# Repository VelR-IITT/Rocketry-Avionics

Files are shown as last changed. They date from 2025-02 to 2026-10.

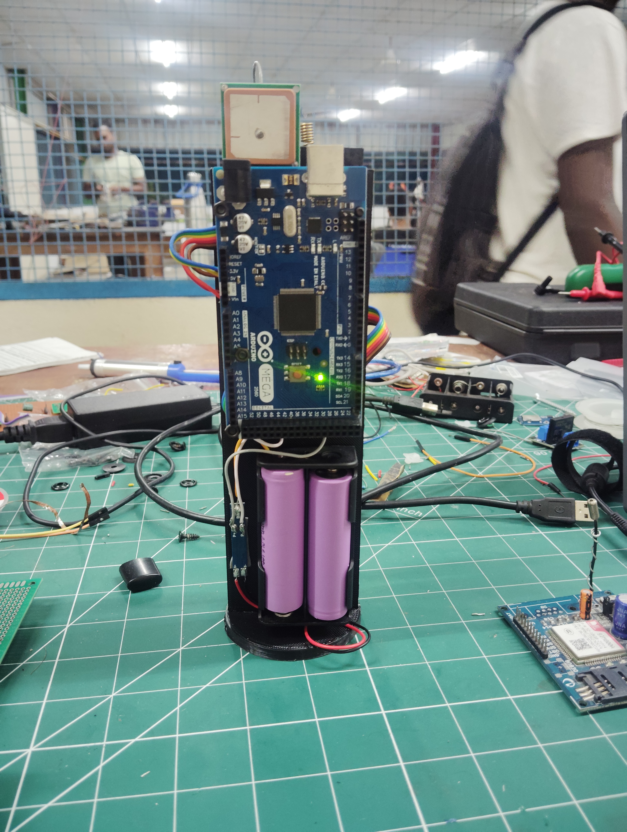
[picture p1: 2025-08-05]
Images and Files/actual/IMG_20250521_003605 (1).jpg

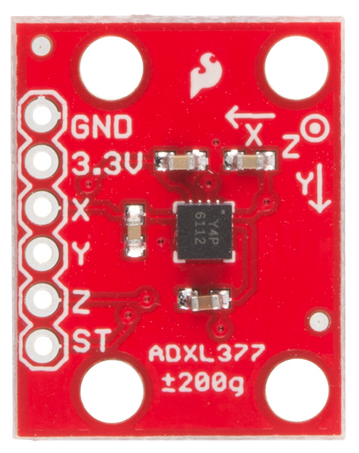
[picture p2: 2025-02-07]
Images and Files/actual/ADXL377-actual.png

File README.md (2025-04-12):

# Rocketry-Avionics 🚀

Welcome to the **Rocketry-Avionics** repository! This project is dedicated to the development of avionics systems for rocketry. It contains all the necessary files, code, and documentation to help you understand, build, and contribute to the project. 
---
## 📁 Repository Contents

This repository contains the following:

### 1. **Images** 📷
Contains visual assets, diagrams, and photos related to the project. These images are useful for understanding the design and assembly of components.

### 2. **Files for Components** 📄
Includes schematics, datasheets, and design files for various components used in the avionics system. These files are essential for replicating or modifying the project.

### 3. **Code** 💻
Contains the source code for the avionics system. This includes firmware, scripts, and any software required to operate the rocket's electronics.

### 4. **Instructions** 📝
Step-by-step guides and documentation to help you set up, assemble, and troubleshoot the avionics system.

---

## 📧 Contact

🌐 GitHub: [Pratham Chintamani](https://github.com/prathamchintamani) \
🌐 GitHub: [Pratik Raj](https://github.com/0823pratik)\
🌐 GitHub: [Bhavesh Jain](https://github.com/Bhavesh-Ja1n)

---

Happy building! 🚀✨

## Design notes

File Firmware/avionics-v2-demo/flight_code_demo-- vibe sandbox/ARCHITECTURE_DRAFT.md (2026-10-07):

# Rocketry Avionics V2 - Architecture & Documentation Draft

This document serves as a living scratchpad for architectural decisions, system design, and final documentation for the avionics firmware.

## 1. Flight State Machine

To maximize safety and minimize complexity, the system uses a Command-Controlled State Machine with a Minimum Altitude Lockout.

### States
* **`STATE_GROUND` (Default):**
  * System is safe for handling. 
  * Pyros are strictly software-locked.
  * Barometer task maintains a rolling average (e.g., 1-second window) of the current pressure.
  * Low-rate telemetry and logging.

* **`STATE_FLIGHT` (Armed):**
  * Triggered exclusively via LoRa Uplink Command (`CMD_FLIGHT`).
  * **Zeroing:** At the exact moment the command is received, the current barometer rolling average is locked in as the `ground_reference_pressure`.
  * High-speed logging is active.
  * Apogee detection algorithm actively monitors for deployment conditions.

### Safety Mechanisms
* **Minimum Altitude Lockout:** The apogee detection algorithm will NOT fire pyros unless the calculated Above Ground Level (AGL) altitude exceeds a hardcoded threshold (e.g., 50 meters), preventing pad-deployment due to weather/pressure drift.

## 2. FreeRTOS Task Topology

* **Sensor Tasks:** `IMU_Task`, `Baro_Task`, `ADXL_Task`, `GPS_Task`
  * Poll hardware sensors and push data to the `Data_Queue`.
  * Update global telemetry structures.
* **Logging Tasks (Dual Redundancy):** 
  * `Data_Log_Task` (High Priority): Reads from the primary `Flash_Queue` and writes high-speed binary data to LittleFS (Flash). Once safely in Flash, it passes a copy of the data into a secondary `SD_Queue`.
  * `SD_Log_Task` (Low Priority): Reads from the `SD_Queue` and streams data directly to the SD card in real-time (saving as `/flight_X.bin`). This ensures data survives if power is lost before the post-flight transfer.
  * `Transfer_SD`: Triggered post-flight to dump Flash data to the SD card. Saves the flash dump as `/flight_X_f.bin` to distinguish it from the real-time log. It asserts an `SD_Transfer_Active` flag while running, forcing the `SD_Log_Task` to pause and preventing SD bus collisions.
* **Comm Tasks:**
  * `LoRa_Task`: Transmits global telemetry states and listens for uplink commands.
  * `Cmd_Task`: Processes uplink commands from the `Cmd_Queue`.

## 3. Data Concurrency & IPC
* **Data Tearing Prevention:** Global sensor structs (`latest_baro_data`, `latest_imu_data`, etc.) will be updated and read using FreeRTOS **Critical Sections** (`taskENTER_CRITICAL()` and `taskEXIT_CRITICAL()`).
* **Why:** Disabling interrupts for the nanoseconds it takes to copy a tiny struct is significantly faster and less complex than managing Mutexes or Double-Buffering flags.
* **Golden Rule:** Critical sections must *strictly* contain only memory copy operations. Doing anything slow inside them (like `Serial.print`, SPI transfers, or `delay`) will crash the RTOS or drop hardware interrupts.

## 4. Hardware Interfaces
* **MCU:** Teensy 4.1 (ARM Cortex-M7 with Double-Precision FPU)
* **Barometer:** BMP280 (SPI) - *Note: Utilizes 64-bit `double` compensation math natively on the FPU to bypass compiler bit-shift bugs and maintain max precision.*
* **IMU:** GY-91 / MPU9250 (SPI)
* **High-G Accel:** ADXL (I2C)
* **GPS:** UBLOX (Serial7)
* **Radio:** RFM95 LoRa 866MHz (SPI)
* **Storage:** Onboard LittleFS + Built-in SD Card

## 5. Dual Telemetry & Command Routing (LoRa + GSM)
To ensure maximum communication redundancy, the system uses a Multi-Producer / Single-Consumer queue architecture for commands:
* **Downlink (Telemetry):** Both `LoRa_Task` and `GSM_Task` read the global sensor variables independently (using Critical Sections) and transmit them over their respective links.
* **Uplink (Commands):** Both tasks listen for incoming commands. If a valid command is received on *either* link, it is pushed to the shared `Cmd_Queue`. 
* FreeRTOS natively handles multiple tasks writing to the same queue simultaneously, meaning the `Cmd_Task` doesn't care whether a command arrived via LoRa or GSM—it simply executes it.

## 6. Pyro Management
To prevent blocking critical flight loops, pyro deployment is handled by a dedicated `Pyro_Task`.
* **Mechanism:** The apogee detection logic triggers the pyro by sending a FreeRTOS Task Notification (`xTaskNotifyGive()`) to the `Pyro_Task`.
* **Execution:** Once notified, the `Pyro_Task` double-checks the safety lockouts, sets the ignition pin HIGH, uses `vTaskDelay()` to hold the current for the required burn duration (e.g., 2 seconds), and then pulls the pin LOW. After firing, the task suspends itself permanently.
* **Continuity:** Prior to deployment, the `Pyro_Task` periodically wakes up (e.g., at 1Hz) to read the continuity sense pins and update the global telemetry state.

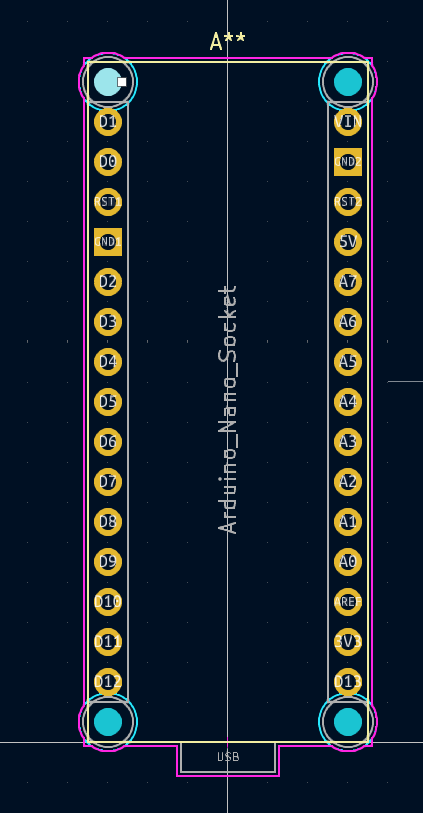
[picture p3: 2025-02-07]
Images and Files/footprints/Arduino_Nano-footprint.png

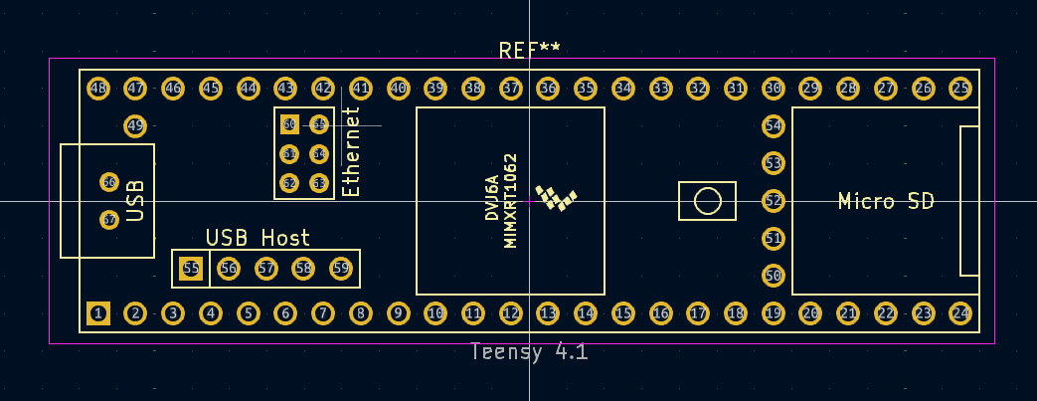
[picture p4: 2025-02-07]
Images and Files/footprints/Teensy_footprint.png

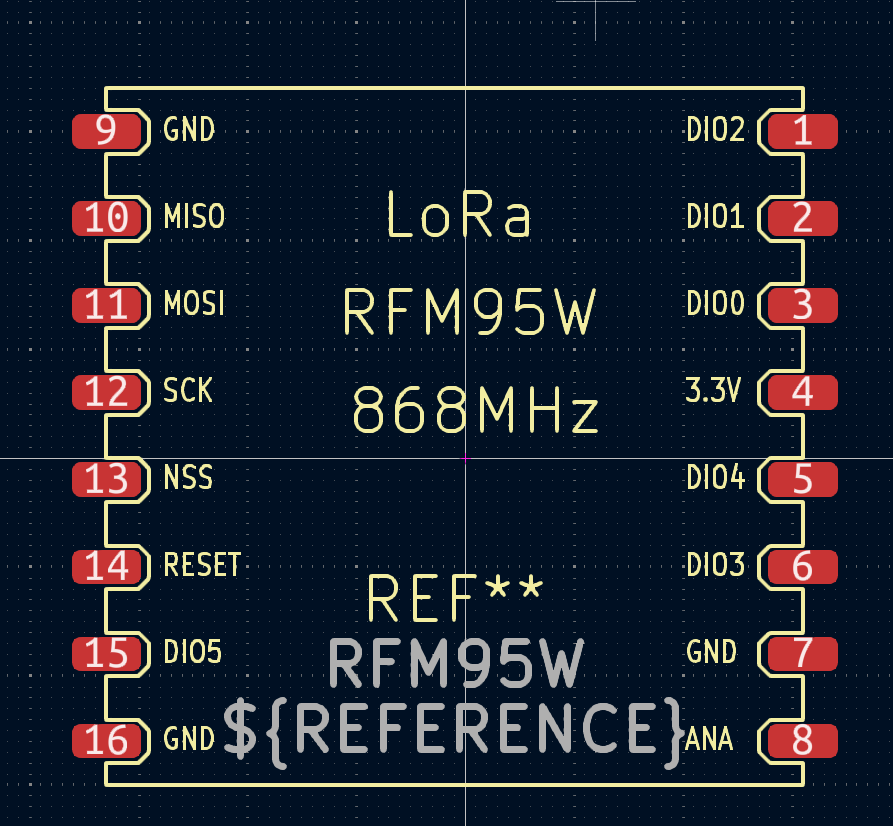
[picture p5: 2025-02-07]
Images and Files/footprints/RFM95W-footprint.png

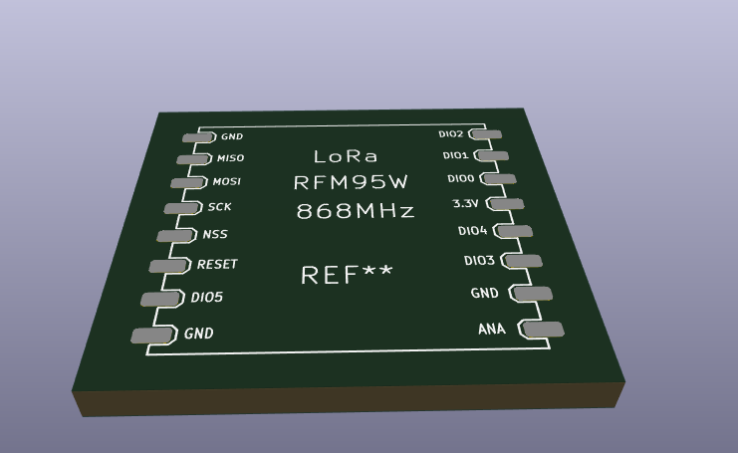
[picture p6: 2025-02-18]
Images and Files/footprints/rmf95w_perspective.png

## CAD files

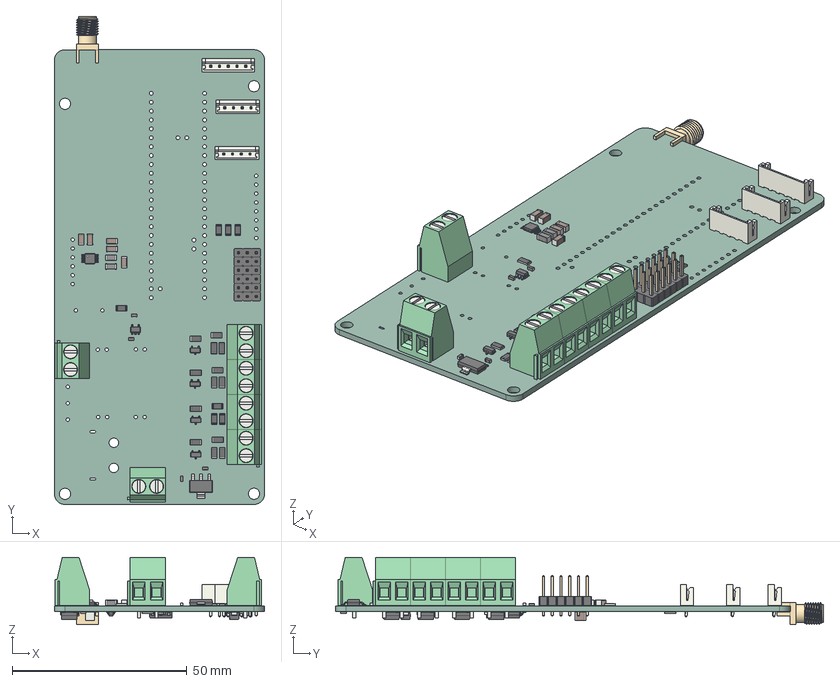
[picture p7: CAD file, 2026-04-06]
Project_Directory/Avionics_Board_Rev_2/Avionics_Board_Rev_2.step
60.1 x 139.5 x 19.2 mm
R_1206_3216Metric x 24
PinHeader_1x03_P2.54mm_Vertical x 6
SOT-23-5
C_1206_3216Metric x 5
SOT-23 x 5
TerminalBlock_Phoenix_MKDS-1,5-2_1x02_P5.00mm_Horizontal x 4
SOT-223 x 2
L_1206_3216Metric x 2
TerminalBlock_Phoenix_MKDS-1,5-2-5.08_1x02_P5.08mm_Horizontal x 2
C_0603_1608Metric x 6
JST_EH_B4B-EH-A_1x04_P2.50mm_Vertical x 2
JST_EH_B5B-EH-A_1x05_P2.50mm_Vertical
TSSOP-10_3x3mm_P0.5mm
C_1210_3225Metric
D_SMA x 5
SMA_Samtec_SMA-J-P-H-ST-EM1_EdgeMount
Avionics_Board_Rev_2_PCB

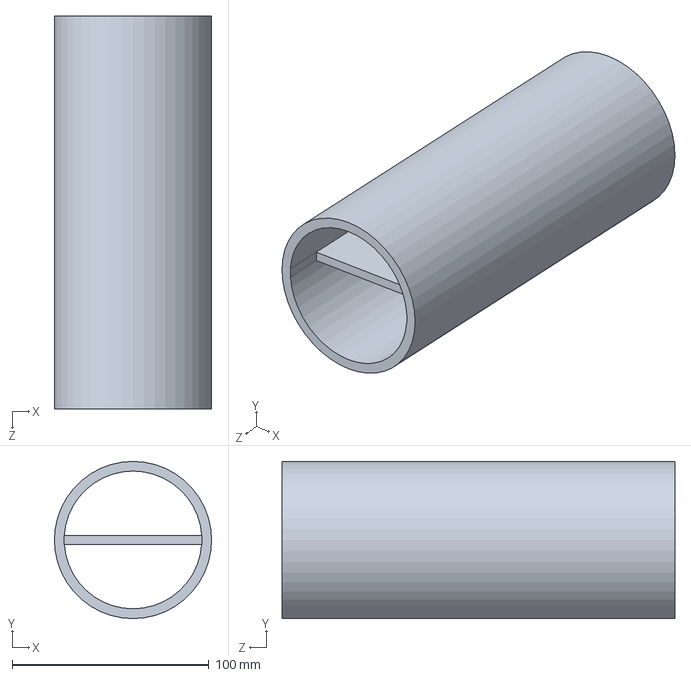
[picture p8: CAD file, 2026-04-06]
Project_Directory/Avionics_Board_Rev_2/Part18.SLDPRT
80.0 x 80.0 x 200.0 mm

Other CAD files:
Project_Directory/Avionics_Board_Rev_2/Avionics_Board_Rev_2.SLDASM

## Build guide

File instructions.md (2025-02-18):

## Steps to Open and Configure the Project  

0. **In the following procedure, opening the same project file may cause problems, please create a new project and proceed.**
1. **Clone the repository**  
2. **Navigate to the project directory:**  
   ```sh
   cd ./Project_Library/on_board_pcb
   ```  
3. **Open the project file (`on_board_pcb.kicad_pro`)**  
   - Double-click `on_board_pcb.kicad_pro` to open it in KiCad.  
   - If that doesn't work, open KiCad, go to the **File** tab, and manually open the `.kicad_pro` file.  

4. **Set Up Symbol Libraries:**  
   - Open the **Schematic Editor**.  
   - Go to **Preferences > Manage Symbol Libraries**.  
   - Add the `.kicad_sym` file located in the `Avionics_Symbols` directory.  
   - Click **Save**.  

5. **Set Up Footprint Libraries:**  
   - Open the **Footprint Editor**.  
   - Go to **Preferences > Manage Footprint Libraries**.  
   - Add the `.pretty` folder located in the `Avionics_Footprints` directory.  
   - Click **Save**.
---

## Important Notes  

- **You are now ready to start building!**  
- If you need to make changes to the repository, **contact [Pratham](https://github.com/prathamchintamani)**.  
- **DO NOT make changes and push to the `main` branch.**

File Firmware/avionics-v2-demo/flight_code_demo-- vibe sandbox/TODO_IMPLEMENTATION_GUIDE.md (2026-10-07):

# Avionics V2 - Implementation Guide & Code Reference

This document outlines the specific code changes required to bring the current `main.cpp` up to the finalized architecture.

## 1. Barometer Math Fix  --- > unresolved implemented this . but the readings are still around 610 
**Problem:** The 64-bit integer formula in `Read_Baro()` is prone to compiler shift bugs on 32-bit ARM, resulting in ~617 hPa.
**Implementation:** Replace the `int64_t` math with native `double` (64-bit FPU) math.
```cpp
// Inside Read_Baro()
double var1, var2, p;
var1 = ((double)t_fine / 2.0) - 64000.0;
var2 = var1 * var1 * ((double)cal.P6) / 32768.0;
var2 = var2 + var1 * ((double)cal.P5) * 2.0;
var2 = (var2 / 4.0) + (((double)cal.P4) * 65536.0);
var1 = (((double)cal.P3) * var1 * var1 / 524288.0 + ((double)cal.P2) * var1) / 524288.0;
var1 = (1.0 + var1 / 32768.0) * ((double)cal.P1);
if (var1 == 0.0) return data; 
p = 1048576.0 - (double)adc_P;
p = (p - (var2 / 4096.0)) * 6250.0 / var1;
var1 = ((double)cal.P9) * p * p / 2147483648.0;
var2 = p * ((double)cal.P8) / 32768.0;
p = p + (var1 + var2 + ((double)cal.P7)) / 16.0;
data.baro.pressure = (float)(p / 100.0);
```

## 2. Pyro Task & Continuity
**Implementation:** Create a dedicated task utilizing `ulTaskNotifyTake` for a hybrid timeout/trigger loop.
```cpp
void Pyro_Task(void *pvParameters) {
    while(1) {
        uint32_t trigger = ulTaskNotifyTake(pdTRUE, pdMS_TO_TICKS(1000)); // 1Hz timeout
        if (trigger > 0) {
            digitalWrite(PYRO_PIN, HIGH);
            vTaskDelay(pdMS_TO_TICKS(2000)); // 2 second burn
            digitalWrite(PYRO_PIN, LOW);
            vTaskDelete(NULL); 
        } else {
            // No trigger -> Check continuity
            int status = analogRead(SENSE_PIN);
            taskENTER_CRITICAL();
            latest_board_data.pyro_state = status;
            taskEXIT_CRITICAL();
        }
    }
}
```

## 3. Data Concurrency
**Implementation:** Wrap all updates to global sensor structs in Critical Sections.
```cpp
taskENTER_CRITICAL();
latest_baro_data = data.baro;
taskEXIT_CRITICAL();
```

## 4. Dual Logging Pipeline
**Implementation:** 
1. Create `QueueHandle_t SD_Queue;`
2. Sensor tasks push to `Data_Queue` (which acts as the Flash queue).
3. `Data_Log_Task` reads from `Data_Queue`, writes to LittleFS, then calls `xQueueSend(SD_Queue, ...)`
4. `SD_Log_Task` reads from `SD_Queue` and writes to `/flight_X.bin`.

## 5. GSM Integration
**Implementation:** 
1. Create `GSM_Task(void *pvParameters)`.
2. Route incoming GSM commands to the existing queue: `xQueueSend(Cmd_Queue, &rx_pkt, 0)`.

## 6. Buzzer Task
**Implementation:** 
Create a low-priority task that reads `latest_board_data.error_code` and `latest_board_data.state`, using `vTaskDelay()` to beep patterns (e.g., 3 fast beeps = No GPS, Solid Tone = Armed).

## 7. Safety Fixes (To Implement)
* **I2C Timeout:** Add `Wire1.setWireTimeout(3000, true);` to prevent the ADXL from freezing the RTOS.
* **Internal Watchdog:** Use the Teensy's internal silicon watchdog (`WDT_T4` library) to reboot if a task deadlocks.

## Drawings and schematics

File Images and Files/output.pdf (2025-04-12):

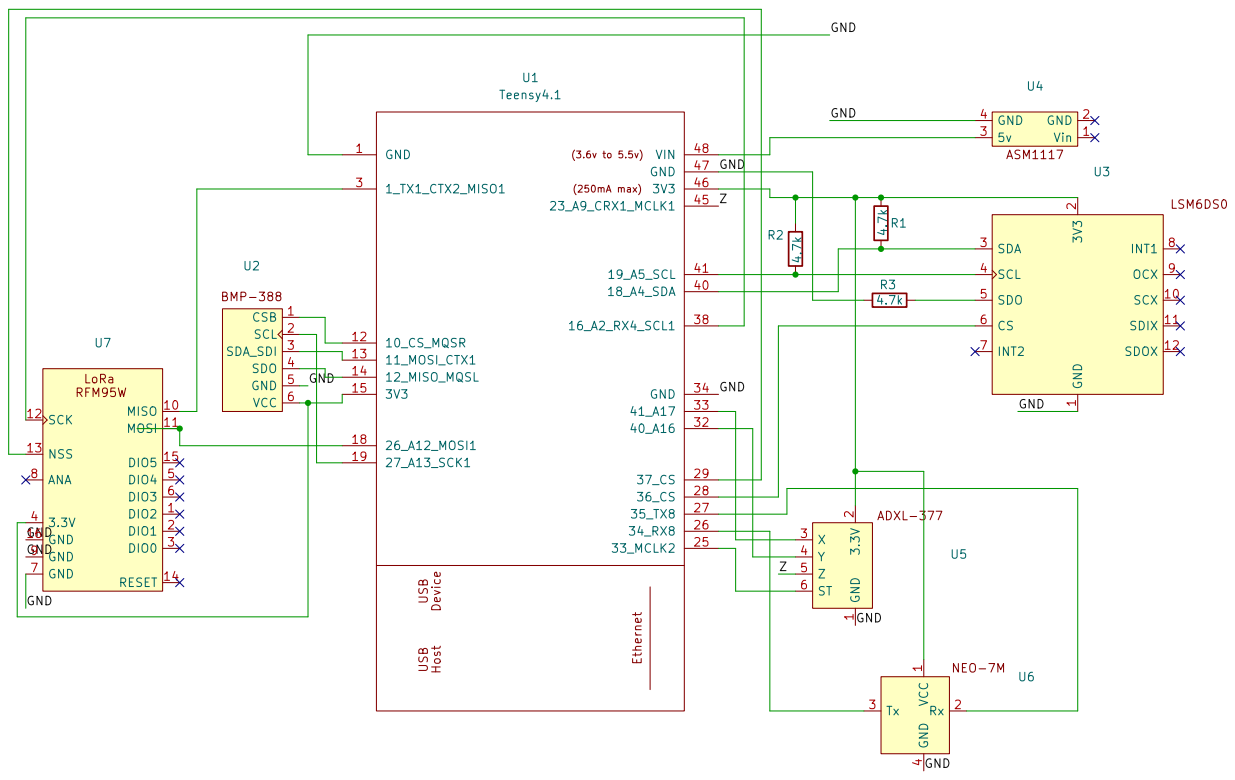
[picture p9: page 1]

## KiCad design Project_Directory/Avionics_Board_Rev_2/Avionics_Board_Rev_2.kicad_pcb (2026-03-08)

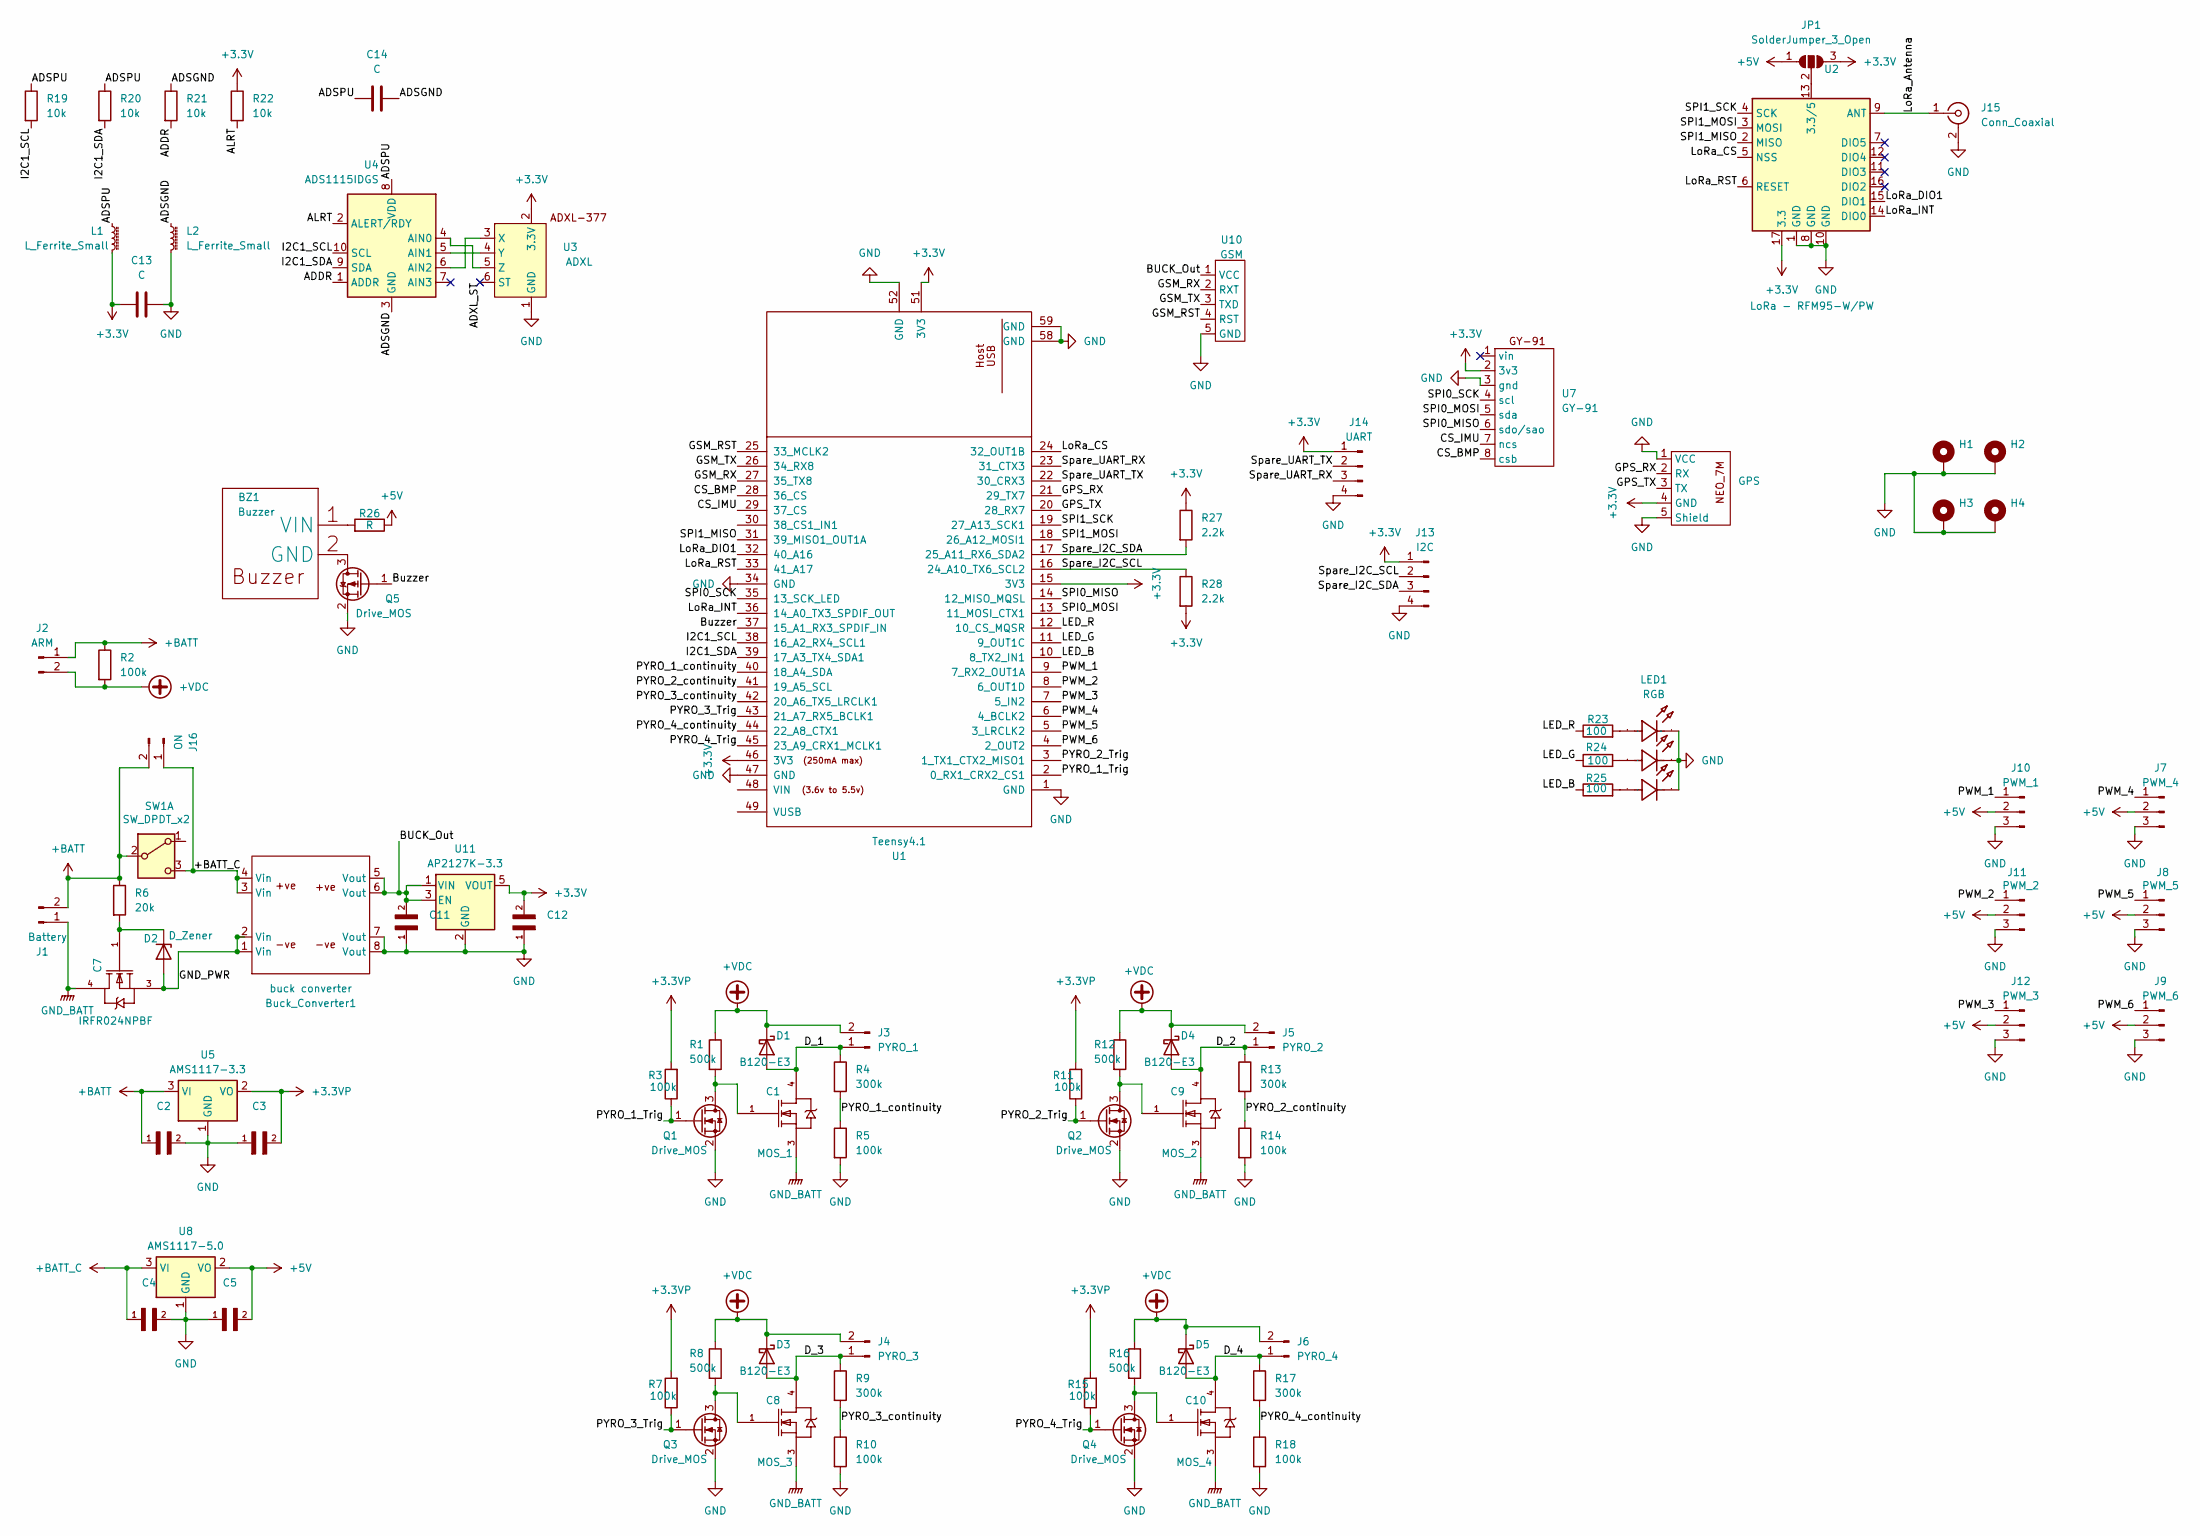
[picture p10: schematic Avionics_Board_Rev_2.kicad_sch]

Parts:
BZ1: Buzzer; Buzzer_TMB12A05
Buck_Converter1: buck converter; buck converter_corrected
C1: MOS_1; IRFR024NTRPBF-HXY Mosfet
C2, C3, C4, C5, C11, C12: C_0603_1608Metric_Pad1.08x0.95mm_HandSolder
C7: IRFR024NPBF; IRFR024NTRPBF-HXY Mosfet
C8: MOS_3; IRFR024NTRPBF-HXY Mosfet
C9: MOS_2; IRFR024NTRPBF-HXY Mosfet
C10: MOS_4; IRFR024NTRPBF-HXY Mosfet
C13: C; C_1206_3216Metric_Pad1.33x1.80mm_HandSolder
C14: C; C_1210_3225Metric_Pad1.33x2.70mm_HandSolder
D1, D3, D4, D5: B120-E3; D_SMA
D2: D_Zener; diode_
H1, H2, H3, H4: MountingHole_Pad; MountingHole_3.2mm_M3_DIN965_Pad_TopBottom
J1: Battery; AMASS_XT60PW-M_1x02_P7.20mm_Horizontal
J2: ARM; TerminalBlock_Phoenix_MKDS-1,5-2-5.08_1x02_P5.08mm_Horizont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
J3: PYRO_1; TerminalBlock_Phoenix_MKDS-1,5-2_1x02_P5.00mm_Horizontal
J4: PYRO_3; TerminalBlock_Phoenix_MKDS-1,5-2_1x02_P5.00mm_Horizontal
J5: PYRO_2; TerminalBlock_Phoenix_MKDS-1,5-2_1x02_P5.00mm_Horizontal
J6: PYRO_4; TerminalBlock_Phoenix_MKDS-1,5-2_1x02_P5.00mm_Horizontal
J7: PWM_4; PinHeader_1x03_P2.54mm_Vertical
J8: PWM_5; PinHeader_1x03_P2.54mm_Vertical
J9: PWM_6; PinHeader_1x03_P2.54mm_Vertical
J10: PWM_1; PinHeader_1x03_P2.54mm_Vertical
J11: PWM_2; PinHeader_1x03_P2.54mm_Vertical
J12: PWM_3; PinHeader_1x03_P2.54mm_Vertical
J13: I2C; JST_EH_B4B-EH-A_1x04_P2.50mm_Vertical
J14: UART; JST_EH_B4B-EH-A_1x04_P2.50mm_Vertical
J15: Conn_Coaxial; SMA_Samtec_SMA-J-P-H-ST-EM1_EdgeMount
J16: ON; TerminalBlock_Phoenix_MKDS-1,5-2-5.08_1x02_P5.08mm_Horizont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
JP1: SolderJumper_3_Open; SolderJumper-3_P2.0mm_Open_TrianglePad1.0x1.5mm
L1, L2: L_Ferrite_Small; L_1206_3216Metric_Pad1.22x1.90mm_HandSolder
LED1: RGB; XL-z3535rgbasg_RGB_LED; Manufacturer Part XL-Z3535RGBA-SG
Q1, Q2, Q3, Q4, Q5: Drive_MOS; SOT-23
R1, R8, R12, R16: 500k; R_1206_3216Metric_Pad1.30x1.75mm_HandSolder
R2, R3, R5, R7, R10, R11, R14, R15, R18: 100k; R_1206_3216Metric_Pad1.30x1.75mm_HandSolder
R4, R9, R13, R17: 300k; R_1206_3216Metric_Pad1.30x1.75mm_HandSolder
R6: 20k; R_1206_3216Metric_Pad1.30x1.75mm_HandSolder
R19, R20, R21, R22: 10k; C_1206_3216Metric_Pad1.33x1.80mm_HandSolder
R23, R24, R25: 100; R_1206_3216Metric_Pad1.30x1.75mm_HandSolder
R26: R; R_1206_3216Metric_Pad1.30x1.75mm_HandSolder
R27, R28: 2.2k; R_1206_3216Metric_Pad1.30x1.75mm_HandSolder
SW1: SW_DPDT_x2; Switch exp
U1: Teensy4.1; Teensy_4.1
U2: LoRa - RFM95-W/PW; RFM95W,PW
U3: ADXL; ADXL377_SparkFun_Module
U4: ADS1115IDGS; TSSOP-10_3x3mm_P0.5mm
U5: AMS1117-3.3; SOT-223-3_TabPin2
U6: GPS; JST-SH 1mm 4 Pin Male E Type Vertical Single Row WTB Connec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
U7: GY-91; gy91
U8: AMS1117-5.0; SOT-223-3_TabPin2
U10: GSM; JST_EH_B5B-EH-A_1x05_P2.50mm_Vertical
U11: AP2127K-3.3; SOT-23-5

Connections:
+3.3V: C12.2, C13.1, J13.1, J14.1, JP1.3 (B), L1.2, R22.1, R27.1, R28.2, U1.15 (3V3), U1.46 (3V3), U1.51 (3V3), U2.17 (3.3), U3.2 (3.3V), U6.4 (GND), U7.2 (3v3), U11.5 (VOUT)
+3.3VP: C3.2, R3.2, R7.2, R11.2, R15.2, U5.2 (VO)
+5V: C5.2, J7.2, J8.2, J9.2, J10.2, J11.2, J12.2, JP1.1 (A), R26.1, U8.2 (VO)
+BATT: C2.1, J1.2, J2.1, J16.2, R2.1, R6.1, SW1.2 (B), U5.3 (VI)
+BATT_C: Buck_Converter1.3 (Vin), Buck_Converter1.4 (Vin), C4.1, J16.1, SW1.3 (C), U8.3 (VI)
+VDC: D1.1 (K), D3.1 (K), D4.1 (K), D5.1 (K), J2.2, J3.2, J4.2, J5.2, J6.2, R1.1, R2.2, R8.1, R12.1, R16.1
/ADDR: R21.2, U4.1 (ADDR)
/ADSGND: C14.2, L2.1, R21.1, U4.3 (GND)
/ADSPU: C14.1, L1.1, R19.1, R20.1, U4.8 (VDD)
/ADXL_ST: U3.6 (ST)
/ALRT: R22.2, U4.2 (ALERT/RDY)
/BUCK_Out: Buck_Converter1.5 (Vout), Buck_Converter1.6 (Vout), C11.2, U10.1 (VCC), U11.1 (VIN), U11.3 (EN)
/Buzzer: Q5.1 (G), U1.37 (15_A1_RX3_SPDIF_IN)
/CS_BMP: U1.28 (36_CS), U7.8 (csb)
/CS_IMU: U1.29 (37_CS), U7.7 (ncs)
/D_1: C1.4, D1.2 (A), J3.1, R4.1
/D_2: C9.4, D4.2 (A), J5.1, R13.1
/D_3: C8.4, D3.2 (A), J4.1, R9.1
/D_4: C10.4, D5.2 (A), J6.1, R17.1
/GND_PWR: Buck_Converter1.1 (Vin), Buck_Converter1.2 (Vin), C7.3, D2.2 (A)
/GPS_RX: U1.21 (29_TX7), U6.2 (RX)
/GPS_TX: U1.20 (28_RX7), U6.3 (TX)
/GSM_RST: U1.25 (33_MCLK2), U10.4 (RST)
/GSM_RX: U1.27 (35_TX8), U10.2 (RXT)
/GSM_TX: U1.26 (34_RX8), U10.3 (TXD)
/I2C1_SCL: R19.2, U1.38 (16_A2_RX4_SCL1), U4.10 (SCL)
/I2C1_SDA: R20.2, U1.39 (17_A3_TX4_SDA1), U4.9 (SDA)
/LED_B: R25.1, U1.10 (8_TX2_IN1)
/LED_G: R24.1, U1.11 (9_OUT1C)
/LED_R: R23.1, U1.12 (10_CS_MQSR)
/LoRa_Antenna: J15.1 (In), U2.9 (ANT)
/LoRa_CS: U1.24 (32_OUT1B), U2.5 (NSS)
/LoRa_DIO1: U1.32 (40_A16), U2.15 (DIO1)
/LoRa_INT: U1.36 (14_A0_TX3_SPDIF_OUT), U2.14 (DIO0)
/LoRa_RST: U1.33 (41_A17), U2.6 (RESET)
/PWM_1: J10.1, U1.9 (7_RX2_OUT1A)
/PWM_2: J11.1, U1.8 (6_OUT1D)
/PWM_3: J12.1, U1.7 (5_IN2)
/PWM_4: J7.1, U1.6 (4_BCLK2)
/PWM_5: J8.1, U1.5 (3_LRCLK2)
/PWM_6: J9.1, U1.4 (2_OUT2)
/PYRO_1_Trig: Q1.1 (G), R3.1, U1.2 (0_RX1_CRX2_CS1)
/PYRO_1_continuity: R4.2, R5.1, U1.40 (18_A4_SDA)
/PYRO_2_Trig: Q2.1 (G), R11.1, U1.3 (1_TX1_CTX2_MISO1)
/PYRO_2_continuity: R13.2, R14.1, U1.41 (19_A5_SCL)
/PYRO_3_Trig: Q3.1 (G), R7.1, U1.43 (21_A7_RX5_BCLK1)
/PYRO_3_continuity: R9.2, R10.1, U1.42 (20_A6_TX5_LRCLK1)
/PYRO_4_Trig: Q4.1 (G), R15.1, U1.45 (23_A9_CRX1_MCLK1)
/PYRO_4_continuity: R17.2, R18.1, U1.44 (22_A8_CTX1)
/SPI0_MISO: U1.14 (12_MISO_MQSL), U7.6 (sdo/sao)
/SPI0_MOSI: U1.13 (11_MOSI_CTX1), U7.5 (sda)
/SPI0_SCK: U1.35 (13_SCK_LED), U7.4 (scl)
/SPI1_MISO: U1.31 (39_MISO1_OUT1A), U2.2 (MISO)
/SPI1_MOSI: U1.18 (26_A12_MOSI1), U2.3 (MOSI)
/SPI1_SCK: U1.19 (27_A13_SCK1), U2.4 (SCK)
/Spare_I2C_SCL: J13.2, R28.1, U1.16 (24_A10_TX6_SCL2)
/Spare_I2C_SDA: J13.3, R27.2, U1.17 (25_A11_RX6_SDA2)
/Spare_UART_RX: J14.3, U1.23 (31_CTX3)
/Spare_UART_TX: J14.2, U1.22 (30_CRX3)
GND: Buck_Converter1.7 (Vout), Buck_Converter1.8 (Vout), C2.2, C3.1, C4.2, C5.1, C11.1, C12.1, C13.2, H1.1, H2.1, H3.1, H4.1, J7.3, J8.3, J9.3, J10.3, J11.3, J12.3, J13.4, J14.4, J15.2 (Ext), L2.2, LED1.1 (-), LED1.2 (-), LED1.3 (1), Q1.2 (S), Q2.2 (S), Q3.2 (S), Q4.2 (S), Q5.2 (S), R5.2, R10.2, R14.2, R18.2, U1.1 (GND), U1.34 (GND), U1.47 (GND), U1.52 (GND), U1.58 (GND), U1.59 (GND), U2.1 (GND), U2.8 (GND), U2.10 (GND), U3.1 (GND), U5.1 (GND), U6.1 (VCC), U6.5 (Shield), U7.3 (gnd), U8.1 (GND), U10.5 (GND), U11.2 (GND)
GND_BATT: C1.3, C7.4, C8.3, C9.3, C10.3, J1.1
unnamed: BZ1.2 (GND), Q5.3 (D)
unnamed: BZ1.1 (VIN), R26.2
unnamed: C7.1, D2.1 (K), R6.2
unnamed: JP1.2 (C), U2.13 (3.3/5)
unnamed: LED1.4 (+), R23.2
unnamed: LED1.5 (+), R24.2
unnamed: LED1.6 (+), R25.2
unnamed: C1.1, Q1.3 (D), R1.2
unnamed: C9.1, Q2.3 (D), R12.2
unnamed: C8.1, Q3.3 (D), R8.2
unnamed: C10.1, Q4.3 (D), R16.2
unnamed: U3.3 (X), U4.6 (AIN2)
unnamed: U3.4 (Y), U4.5 (AIN1)
unnamed: U3.5 (Z), U4.4 (AIN0)

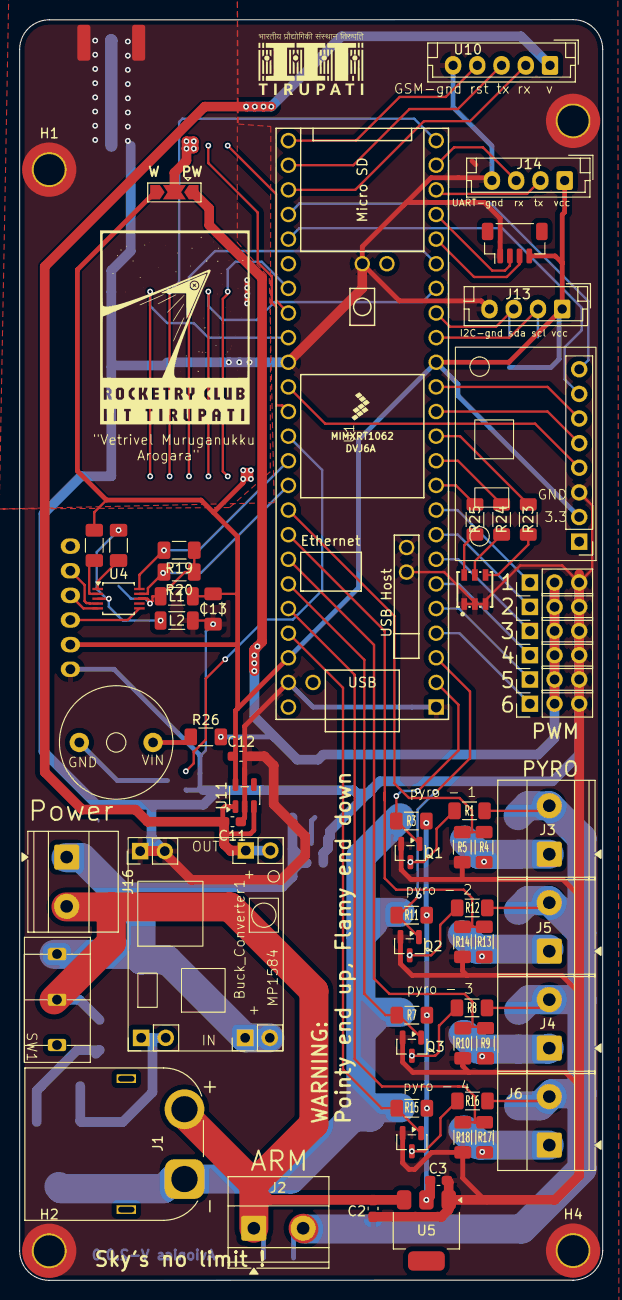
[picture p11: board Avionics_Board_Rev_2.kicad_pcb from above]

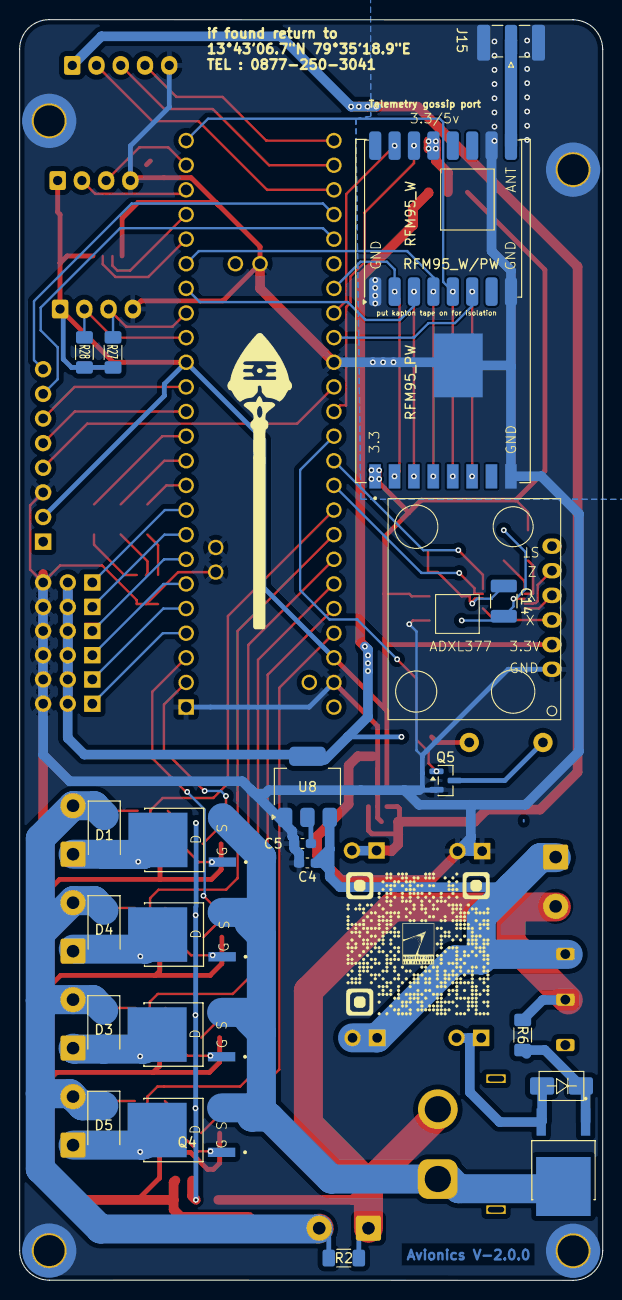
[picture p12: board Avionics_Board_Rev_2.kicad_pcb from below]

Board: 2 copper layers, 60.1 x 130.0 mm, 88 parts (22 on the bottom side), 74 nets.

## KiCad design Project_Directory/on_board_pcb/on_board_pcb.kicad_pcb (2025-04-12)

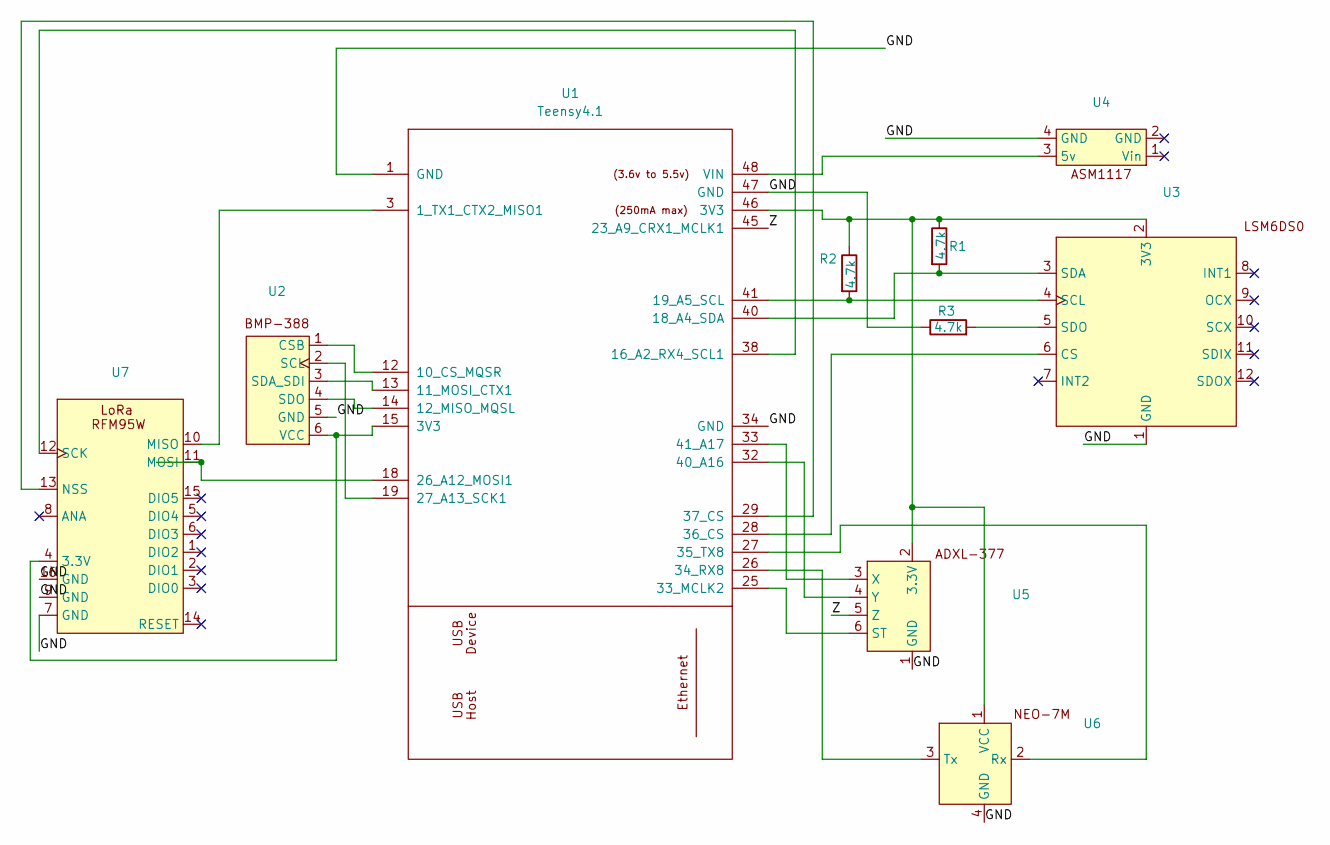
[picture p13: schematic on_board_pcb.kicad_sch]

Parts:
R1, R2, R3: 4.7k; R_Axial_DIN0207_L6.3mm_D2.5mm_P7.62mm_Horizontal
U1: Teensy4.1; Teensy-4.1
U2: BMP388
U3: LSM6DS0
U4: AMS1117
U5: ADXL377
U6: NEO_7M
U7: RFM95W

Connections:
/GND: R3.1, U1.1 (GND), U1.34 (GND), U1.47 (GND), U2.5 (GND), U3.1 (GND), U4.4 (GND), U5.1 (GND), U6.4 (GND), U7.7 (GND), U7.9 (GND), U7.16 (GND)
/Z: U1.45 (23_A9_CRX1_MCLK1), U5.5 (Z)
unnamed: U1.3 (1_TX1_CTX2_MISO1), U7.10 (MISO)
unnamed: U1.12 (10_CS_MQSR), U2.1 (CSB)
unnamed: U1.13 (11_MOSI_CTX1), U2.3 (SDA_SDI)
unnamed: U1.14 (12_MISO_MQSL), U2.4 (SDO)
unnamed: U1.38 (16_A2_RX4_SCL1), U7.12 (SCK)
unnamed: R1.2, U1.40 (18_A4_SDA), U3.3 (SDA)
unnamed: R2.2, U1.41 (19_A5_SCL), U3.4 (SCL)
unnamed: U1.18 (26_A12_MOSI1), U7.11 (MOSI)
unnamed: U1.19 (27_A13_SCK1), U2.2 (SCL)
unnamed: U1.25 (33_MCLK2), U5.6 (ST)
unnamed: U1.26 (34_RX8), U6.3 (Tx)
unnamed: U1.27 (35_TX8), U6.2 (Rx)
unnamed: U1.28 (36_CS), U3.6 (CS)
unnamed: U1.29 (37_CS), U7.13 (NSS)
unnamed: U1.32 (40_A16), U5.4 (Y)
unnamed: U1.33 (41_A17), U5.3 (X)
unnamed: U1.48 (VIN), U4.3 (5v)
unnamed: U1.15 (3V3), U2.6 (VCC), U7.4 (3.3V)
unnamed: R1.1, R2.1, U1.46 (3V3), U3.2 (3V3), U5.2 (3.3V), U6.1 (VCC)
unnamed: R3.2, U3.5 (SDO)

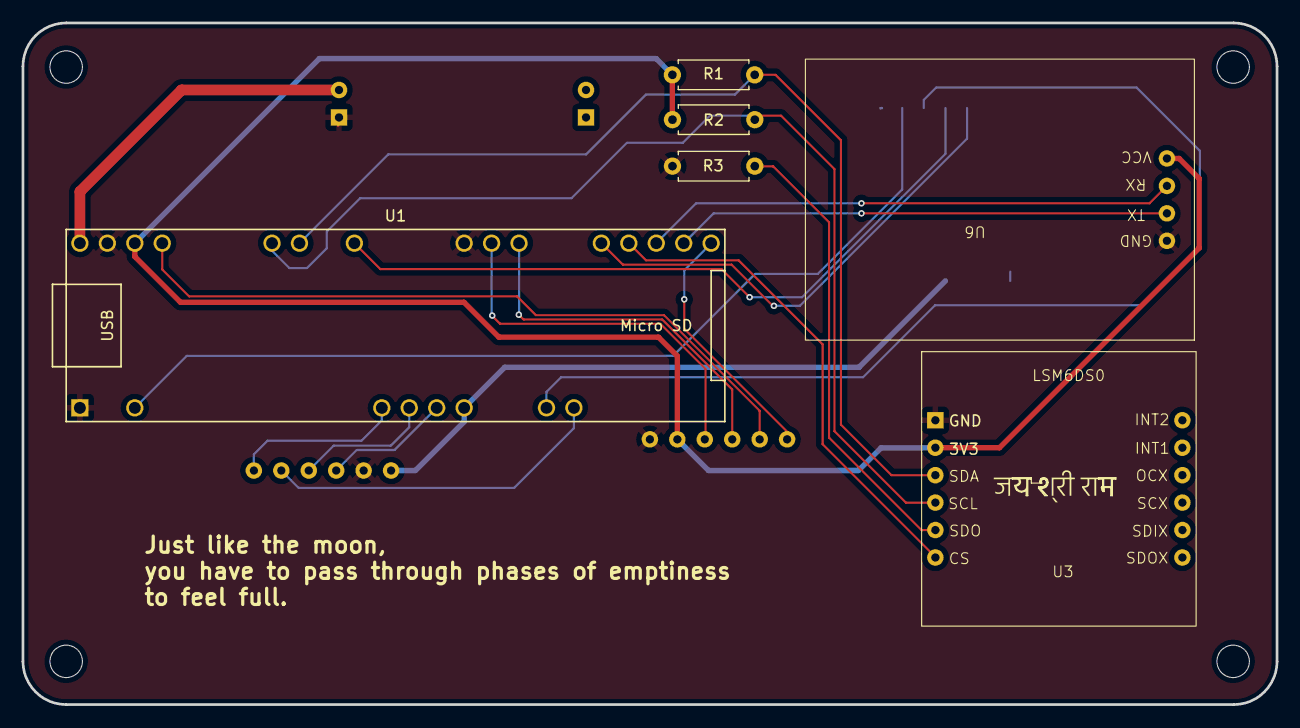
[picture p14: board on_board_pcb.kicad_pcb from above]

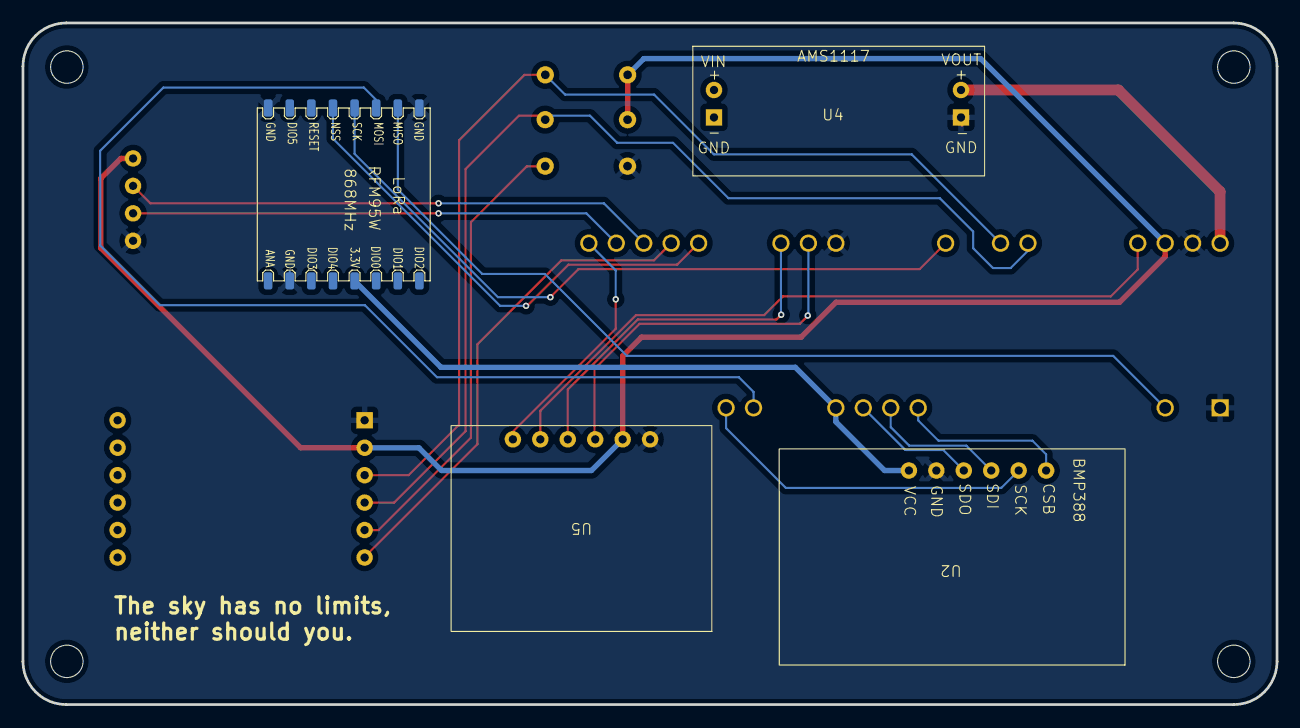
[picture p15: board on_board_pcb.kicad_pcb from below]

Board: 2 copper layers, 116.1 x 63.1 mm, 10 parts (4 on the bottom side), 22 nets.

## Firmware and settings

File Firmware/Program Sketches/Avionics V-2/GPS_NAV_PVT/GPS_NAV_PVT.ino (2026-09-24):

/*
  Teensy 4.1 + u-blox NEO-7M : UBX configuration + NAV-PVT parser

  Sequence
    1. Find the module's current baud rate (probe with a UBX-MON-VER poll)
    2. Optionally load factory defaults (UBX-CFG-CFG)
    3. Switch module UART1 to TARGET_BAUD (115200)
    4. Disable all NMEA sentences
    5. Enable UBX-NAV-PVT on UART1
    6. Set measurement rate to 10 Hz
    7. Optional: airborne <4g dynamic model, save config to flash/BBR
    8. Parse NAV-PVT continuously, print a summary on USB serial at 1 Hz

  Wiring (Serial7)
    Teensy pin 28 (RX7)  <-  GPS TX
    Teensy pin 29 (TX7)  ->  GPS RX
    GND                  <->  GND
*/

#include <Arduino.h>

// ============================================================ user settings
#define GPS_SERIAL Serial7                    // change to Serial1 etc. if rewired

static const uint32_t TARGET_BAUD     = 115200;   // 10 Hz NAV-PVT needs > 9600
static const uint32_t PRINT_PERIOD_MS = 1000;     // USB report interval

static const bool LOAD_DEFAULTS_FIRST = true;     // UBX-CFG-CFG clear+load defaults
static const bool AIRBORNE_MODE       = true;     // UBX-CFG-NAV5 dynModel 8 (<4g)
static const bool SAVE_CONFIG         = false;    // UBX-CFG-CFG save (flash wear!)

// ============================================================ UBX constants
enum : uint8_t {
  UBX_CLS_NAV = 0x01, UBX_CLS_ACK = 0x05, UBX_CLS_CFG = 0x06, UBX_CLS_MON = 0x0A,
  UBX_NAV_PVT = 0x07,
  UBX_ACK_NAK = 0x00, UBX_ACK_ACK = 0x01,
  UBX_CFG_PRT = 0x00, UBX_CFG_MSG = 0x01, UBX_CFG_RATE = 0x08,
  UBX_CFG_CFG = 0x09, UBX_CFG_NAV5 = 0x24,
  UBX_MON_VER = 0x04
};

// Payloads only - header, length and checksum are generated in sendUBX()

// UBX-CFG-CFG: clearMask FFFF, saveMask 0, loadMask FFFF, devices BBR+Flash
static const uint8_t PL_LOAD_DEFAULTS[] = {
  0xFF, 0xFF, 0x00, 0x00,   0x00, 0x00, 0x00, 0x00,   0xFF, 0xFF, 0x00, 0x00,   0x03 };

// UBX-CFG-CFG: save all to BBR + Flash + EEPROM + SPI flash
static const uint8_t PL_SAVE_CONFIG[] = {
  0x00, 0x00, 0x00, 0x00,   0xFF, 0xFF, 0x00, 0x00,   0x00, 0x00, 0x00, 0x00,   0x17 };

// UBX-CFG-RATE: measRate 100 ms, navRate 1, timeRef GPS
static const uint8_t PL_RATE_10HZ[] = { 0x64, 0x00,  0x01, 0x00,  0x01, 0x00 };

// UBX-CFG-MSG: NAV-PVT, rate 1 on UART1 only  (order: DDC, UART1, UART2, USB, SPI, res)
static const uint8_t PL_ENABLE_PVT[] = { 0x01, 0x07,  0x00, 0x01, 0x00, 0x00, 0x00, 0x00 };

// UBX-CFG-NAV5: dynModel 8 (airborne <4g), fixMode auto 2D/3D
static const uint8_t PL_NAV5_AIRBORNE[] = {
  0xFF, 0xFF, 0x08, 0x03,   0x00, 0x00, 0x00, 0x00,   0x10, 0x27, 0x00, 0x00,
  0x05, 0x00, 0xFA, 0x00,   0xFA, 0x00, 0x64, 0x00,   0x2C, 0x01, 0x00, 0x3C,
  0x00, 0x00, 0x00, 0x00,   0x00, 0x00, 0x00, 0x00,   0x00, 0x00, 0x00, 0x00 };

// Standard NMEA sentences (class 0xF0) to switch off on all ports
struct NmeaMsg { uint8_t id; const char *name; };
static const NmeaMsg NMEA_MSGS[] = {
  {0x00, "GGA"}, {0x01, "GLL"}, {0x02, "GSA"},
  {0x03, "GSV"}, {0x04, "RMC"}, {0x05, "VTG"} };

// ============================================================ parser state
static uint8_t  rxState = 0;
static uint8_t  rxCls, rxId, ckA, ckB;
static uint16_t rxLen, rxIdx;
static uint8_t  rxBuf[128];

static uint32_t framesOk  = 0;
static uint32_t framesBad = 0;

static uint8_t  ackCls = 0, ackId = 0;
static uint8_t  ackResult = 0;            // 0 waiting, 1 ACK, 2 NAK

static uint32_t gpsBaud = 9600;

// ============================================================ NAV-PVT data
struct Pvt {
  uint32_t iTOW;                          // ms
  uint16_t year;
  uint8_t  month, day, hour, minute, second;
  uint8_t  valid;                         // bit0 date, bit1 time, bit2 fully resolved
  uint32_t tAcc;                          // ns
  int32_t  nano;                          // ns
  uint8_t  fixType;
  uint8_t  flags;                         // bit0 gnssFixOK, bit1 diffSoln
  uint8_t  numSV;
  int32_t  lon, lat;                      // 1e-7 deg
  int32_t  height, hMSL;                  // mm
  uint32_t hAcc, vAcc;                    // mm
  int32_t  velN, velE, velD, gSpeed;      // mm/s
  int32_t  headMot;                       // 1e-5 deg
  uint32_t sAcc;                          // mm/s
  uint32_t headAcc;                       // 1e-5 deg
  uint16_t pDOP;                          // 0.01
};

static Pvt      pvt;
static bool     havePvt      = false;
static uint32_t pvtWindow    = 0;         // frames since last report
static uint32_t lastPvtMs    = 0;
static uint32_t lastReportMs = 0;

// ============================================================ helpers
static inline uint16_t rdU16(const uint8_t *p) { return (uint16_t)(p[0] | (p[1] << 8)); }
static inline uint32_t rdU32(const uint8_t *p) {
  return (uint32_t)p[0] | ((uint32_t)p[1] << 8) | ((uint32_t)p[2] << 16) | ((uint32_t)p[3] << 24);
}
static inline int32_t rdI32(const uint8_t *p) { return (int32_t)rdU32(p); }

static inline void ckAdd(uint8_t b) { ckA += b; ckB += ckA; }

static int64_t abs64(int64_t v) { return v < 0 ? -v : v; }

// Print an integer scaled by 10^decimals without using float printf
static void printScaled(int64_t v, uint8_t decimals) {
  if (v < 0) { Serial.print('-'); v = -v; }
  int64_t div = 1;
  for (uint8_t i = 0; i < decimals; i++) div *= 10;
  char buf[24];
  snprintf(buf, sizeof(buf), "%ld", (long)(v / div));
  Serial.print(buf);
  if (decimals) {
    snprintf(buf, sizeof(buf), ".%0*ld", (int)decimals, (long)(v % div));
    Serial.print(buf);
  }
}

// ============================================================ UBX transmit
static void sendUBX(uint8_t cls, uint8_t id, const uint8_t *payload, uint16_t len) {
  uint8_t frame[8 + 64];
  if (len > 64) return;
  frame[0] = 0xB5;
  frame[1] = 0x62;
  frame[2] = cls;
  frame[3] = id;
  frame[4] = len & 0xFF;
  frame[5] = len >> 8;
  if (len) memcpy(&frame[6], payload, len);

  uint8_t a = 0, b = 0;                   // 8-bit Fletcher over class..payload
  for (uint16_t i = 2; i < 6u + len; i++) { a += frame[i]; b += a; }
  frame[6 + len] = a;
  frame[7 + len] = b;

  GPS_SERIAL.write(frame, 8u + len);
  GPS_SERIAL.flush();
}

// ============================================================ UBX receive
static void decodePvt(const uint8_t *p) {
  pvt.iTOW    = rdU32(p + 0);
  pvt.year    = rdU16(p + 4);
  pvt.month   = p[6];
  pvt.day     = p[7];
  pvt.hour    = p[8];
  pvt.minute  = p[9];
  pvt.second  = p[10];
  pvt.valid   = p[11];
  pvt.tAcc    = rdU32(p + 12);
  pvt.nano    = rdI32(p + 16);
  pvt.fixType = p[20];
  pvt.flags   = p[21];
  pvt.numSV   = p[23];
  pvt.lon     = rdI32(p + 24);
  pvt.lat     = rdI32(p + 28);
  pvt.height  = rdI32(p + 32);
  pvt.hMSL    = rdI32(p + 36);
  pvt.hAcc    = rdU32(p + 40);
  pvt.vAcc    = rdU32(p + 44);
  pvt.velN    = rdI32(p + 48);
  pvt.velE    = rdI32(p + 52);
  pvt.velD    = rdI32(p + 56);
  pvt.gSpeed  = rdI32(p + 60);
  pvt.headMot = rdI32(p + 64);
  pvt.sAcc    = rdU32(p + 68);
  pvt.headAcc = rdU32(p + 72);
  pvt.pDOP    = rdU16(p + 76);

  havePvt   = true;
  lastPvtMs = millis();
  pvtWindow++;
}

static void onUbxFrame() {
  framesOk++;
  // NEO-7M (protocol 14) sends an 84-byte NAV-PVT, M8 and later send 92 bytes.
  // All fields used here sit in the first 84 bytes, so accept either.
  if (rxCls == UBX_CLS_NAV && rxId == UBX_NAV_PVT && rxLen >= 84 && rxLen <= sizeof(rxBuf)) {
    decodePvt(rxBuf);
  } else if (rxCls == UBX_CLS_ACK && rxLen == 2 && rxBuf[0] == ackCls && rxBuf[1] == ackId) {
    ackResult = (rxId == UBX_ACK_ACK) ? 1 : 2;
  }
}

static void ubxFeed(uint8_t b) {
  switch (rxState) {
    case 0: if (b == 0xB5) rxState = 1; break;
    case 1: if (b == 0x62) rxState = 2; else if (b != 0xB5) rxState = 0; break;
    case 2: rxCls = b; ckA = 0; ckB = 0; ckAdd(b); rxState = 3; break;
    case 3: rxId = b; ckAdd(b); rxState = 4; break;
    case 4: rxLen = b; ckAdd(b); rxState = 5; break;
    case 5:
      rxLen |= (uint16_t)b << 8;
      ckAdd(b);
      rxIdx = 0;
      if (rxLen > 512) rxState = 0;              // implausible length, resync
      else rxState = rxLen ? 6 : 7;
      break;
    case 6:
      if (rxIdx < sizeof(rxBuf)) rxBuf[rxIdx] = b;
      rxIdx++;
      ckAdd(b);
      if (rxIdx >= rxLen) rxState = 7;
      break;
    case 7:
      if (b == ckA) rxState = 8;
      else { framesBad++; rxState = 0; }
      break;
    case 8:
      if (b == ckB) onUbxFrame();
      else framesBad++;
      rxState = 0;
      break;
  }
}

static inline void pumpGps() {
  while (GPS_SERIAL.available()) ubxFeed((uint8_t)GPS_SERIAL.read());
}

// ============================================================ setup helpers
// Send a config message and wait for UBX-ACK
static bool sendAcked(uint8_t cls, uint8_t id, const uint8_t *pl, uint16_t len, const char *label) {
  for (uint8_t attempt = 0; attempt < 3; attempt++) {
    ackCls = cls; ackId = id; ackResult = 0;
    sendUBX(cls, id, pl, len);
    uint32_t t0 = millis();
    while (millis() - t0 < 500 && ackResult == 0) pumpGps();
    if (ackResult == 1) { Serial.printf("  [ OK  ] %s\n", label); return true; }
    if (ackResult == 2) { Serial.printf("  [ NAK ] %s\n", label); return false; }
  }
  Serial.printf("  [ TIMEOUT ] %s\n", label);
  return false;
}

// Open GPS_SERIAL at `baud` and see whether any valid UBX frame comes back
static bool probeBaud(uint32_t baud) {
  GPS_SERIAL.begin(baud);
  delay(30);
  while (GPS_SERIAL.available()) GPS_SERIAL.read();
  rxState = 0;

  uint32_t before = framesOk;
  sendUBX(UBX_CLS_MON, UBX_MON_VER, nullptr, 0);         // poll: module answers if baud matches

  uint32_t timeout = (baud <= 19200) ? 1000 : 400;       // NMEA bursts delay the reply at low baud
  uint32_t t0 = millis();
  while (millis() - t0 < timeout) {
    pumpGps();
    if (framesOk != before) return true;
  }
  return false;
}

static bool detectBaud() {
  static const uint32_t candidates[] = { TARGET_BAUD, 9600, 115200, 38400, 57600, 19200, 4800, 230400 };
  for (size_t i = 0; i < sizeof(candidates) / sizeof(candidates[0]); i++) {
    if (i > 0 && candidates[i] == TARGET_BAUD) continue;
    Serial.printf("  probing %lu baud ... ", (unsigned long)candidates[i]);
    if (probeBaud(candidates[i])) {
      Serial.println("found");
      gpsBaud = candidates[i];
      return true;
    }
    Serial.println("no reply");
  }
  return false;
}

static void waitForModule() {
  while (!detectBaud()) {
    Serial.println("No UBX reply on any baud rate. Check TX/RX crossover, GND and power. Retrying...");
    delay(1000);
  }
  Serial.printf("Module found at %lu baud\n", (unsigned long)gpsBaud);
}

// UBX-CFG-PRT for UART1 (8N1, UBX+NMEA+RTCM in, UBX+NMEA out), then follow with the Teensy side
static bool switchBaud(uint32_t newBaud) {
  uint8_t pl[20] = {0};
  pl[0]  = 0x01;                                   // portID = UART1
  pl[4]  = 0xD0; pl[5] = 0x08;                     // mode = 0x000008D0 (8N1)
  pl[8]  = (uint8_t)(newBaud);
  pl[9]  = (uint8_t)(newBaud >> 8);
  pl[10] = (uint8_t)(newBaud >> 16);
  pl[11] = (uint8_t)(newBaud >> 24);
  pl[12] = 0x07;                                   // inProtoMask  : UBX | NMEA | RTCM
  pl[14] = 0x03;                                   // outProtoMask : UBX | NMEA

  uint32_t oldBaud = gpsBaud;
  for (uint8_t attempt = 0; attempt < 3; attempt++) {
    sendUBX(UBX_CLS_CFG, UBX_CFG_PRT, pl, sizeof(pl));
    delay(100);
    if (probeBaud(newBaud)) { gpsBaud = newBaud; return true; }
    probeBaud(oldBaud);                            // module did not switch, go back and retry
  }
  return false;
}

// ============================================================ setup
void setup() {
  Serial.begin(115200);                            // USB, baud value is ignored
  uint32_t t0 = millis();
  while (!Serial && millis() - t0 < 4000) {}       // give the terminal time to connect

  static uint8_t gpsRxMem[2048];
  static uint8_t gpsTxMem[512];
  GPS_SERIAL.addMemoryForRead(gpsRxMem, sizeof(gpsRxMem));
  GPS_SERIAL.addMemoryForWrite(gpsTxMem, sizeof(gpsTxMem));

  Serial.println();
  Serial.println("=== NEO-7M configuration ===");
  waitForModule();

  if (LOAD_DEFAULTS_FIRST) {
    Serial.println("Loading factory defaults (module will fall back to 9600 baud)");
    sendUBX(UBX_CLS_CFG, UBX_CFG_CFG, PL_LOAD_DEFAULTS, sizeof(PL_LOAD_DEFAULTS));
    delay(1000);
    waitForModule();
  }

  if (gpsBaud != TARGET_BAUD) {
    Serial.printf("Switching module to %lu baud\n", (unsigned long)TARGET_BAUD);
    while (!switchBaud(TARGET_BAUD)) {
      Serial.println("  baud switch failed, retrying...");
      waitForModule();
    }
  }
  Serial.printf("  [ OK  ] link at %lu baud\n", (unsigned long)gpsBaud);

  Serial.println("Disabling NMEA");
  for (size_t i = 0; i < sizeof(NMEA_MSGS) / sizeof(NMEA_MSGS[0]); i++) {
    uint8_t pl[8] = { 0xF0, NMEA_MSGS[i].id, 0, 0, 0, 0, 0, 0 };   // rate 0 on every port
    char label[24];
    snprintf(label, sizeof(label), "NMEA %s off", NMEA_MSGS[i].name);
    sendAcked(UBX_CLS_CFG, UBX_CFG_MSG, pl, sizeof(pl), label);
  }

  Serial.println("Enabling output");
  sendAcked(UBX_CLS_CFG, UBX_CFG_MSG, PL_ENABLE_PVT, sizeof(PL_ENABLE_PVT), "UBX-NAV-PVT on UART1");
  sendAcked(UBX_CLS_CFG, UBX_CFG_RATE, PL_RATE_10HZ, sizeof(PL_RATE_10HZ), "Rate 10 Hz");

  if (AIRBORNE_MODE)
    sendAcked(UBX_CLS_CFG, UBX_CFG_NAV5, PL_NAV5_AIRBORNE, sizeof(PL_NAV5_AIRBORNE), "Dynamic model: airborne <4g");

  if (SAVE_CONFIG)
    sendAcked(UBX_CLS_CFG, UBX_CFG_CFG, PL_SAVE_CONFIG, sizeof(PL_SAVE_CONFIG), "Save config");

  Serial.println("Configuration done, parsing NAV-PVT...");
  lastReportMs = millis();
  pvtWindow = 0;
}

// ============================================================ report
static const char *FIX_NAMES[] = { "No fix", "Dead reckoning", "2D", "3D", "GNSS + dead reckoning", "Time only" };

static void printReport(uint32_t now) {
  uint32_t dt = now - lastReportMs;
  lastReportMs = now;
  uint32_t rate10 = dt ? (pvtWindow * 10000UL) / dt : 0;      // in 0.1 Hz units
  pvtWindow = 0;

  Serial.println();
  Serial.println("=============== UBX-NAV-PVT ===============");

  if (!havePvt) {
    Serial.printf("Waiting for NAV-PVT... (valid UBX frames: %lu, bad: %lu)\n",
                  (unsigned long)framesOk, (unsigned long)framesBad);
    return;
  }
  if (now - lastPvtMs > 2000) Serial.println("WARNING: no NAV-PVT for over 2 s, showing last data");

  Pvt p = pvt;                                                // snapshot

  Serial.printf("Time (UTC)  : %04u-%02u-%02u %02u:%02u:%02u.%03lu   [date:%c time:%c resolved:%c]\n",
                p.year, p.month, p.day, p.hour, p.minute, p.second,
                (unsigned long)(p.iTOW % 1000),
                (p.valid & 1) ? 'Y' : 'N', (p.valid & 2) ? 'Y' : 'N', (p.valid & 4) ? 'Y' : 'N');

  Serial.printf("Fix         : %s  (fixOK:%c  DGPS:%c)   Sats: %u   pDOP: ",
                (p.fixType < 6) ? FIX_NAMES[p.fixType] : "?",
                (p.flags & 1) ? 'Y' : 'N', (p.flags & 2) ? 'Y' : 'N', p.numSV);
  printScaled(p.pDOP, 2);
  Serial.println();

  Serial.print("Latitude    : ");
  printScaled(abs64(p.lat), 7);
  Serial.printf(" deg %c\n", p.lat >= 0 ? 'N' : 'S');

  Serial.print("Longitude   : ");
  printScaled(abs64(p.lon), 7);
  Serial.printf(" deg %c\n", p.lon >= 0 ? 'E' : 'W');

  Serial.print("Altitude    : MSL ");
  printScaled(p.hMSL, 3);
  Serial.print(" m   |   ellipsoid ");
  printScaled(p.height, 3);
  Serial.println(" m");

  Serial.print("Accuracy    : horiz ");
  printScaled(p.hAcc, 3);
  Serial.print(" m   vert ");
  printScaled(p.vAcc, 3);
  Serial.print(" m   speed ");
  printScaled(p.sAcc, 3);
  Serial.println(" m/s");

  Serial.print("Ground speed: ");
  printScaled(p.gSpeed, 3);
  Serial.print(" m/s  (");
  printScaled((int64_t)p.gSpeed * 36 / 100, 2);           // mm/s -> 0.01 km/h
  Serial.println(" km/h)");

  Serial.print("Heading     : ");
  printScaled(p.headMot / 1000, 2);                       // 1e-5 deg -> 0.01 deg
  Serial.println(" deg  (course over ground, only meaningful when moving)");

  Serial.print("Vel N/E/D   : ");
  printScaled(p.velN, 3); Serial.print(" / ");
  printScaled(p.velE, 3); Serial.print(" / ");
  printScaled(p.velD, 3); Serial.println(" m/s");

  Serial.print("Link        : ");
  printScaled(rate10, 1);
  Serial.printf(" Hz measured | frames ok: %lu | bad: %lu\n",
                (unsigned long)framesOk, (unsigned long)framesBad);
}

// ============================================================ loop
void loop() {
  pumpGps();

  uint32_t now = millis();
  if (now - lastReportMs >= PRINT_PERIOD_MS) printReport(now);
}

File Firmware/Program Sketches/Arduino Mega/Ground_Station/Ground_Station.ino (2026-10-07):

#include <SPI.h>
#include <RH_RF95.h>
#include <string.h>

#define RF95_CS   10
#define RF95_INT  2
#define RF95_RST  9
#define RF95_FREQ 866.0

// unit scaling for raw packet values (change if your firmware differs)
#define LATLON_DIV    10000000UL   // degrees * 1e7
#define GPS_ALT_DIV   1000UL       // mm -> m
#define BARO_ALT_DIV  1000UL       // mm -> m (use 100UL if cm)

RH_RF95 rf95(RF95_CS, RF95_INT);

#pragma pack(push, 1)

typedef struct {
    uint32_t time;
    uint32_t utc_time;
    int32_t  lat, lon;
    int32_t  gps_alt, baro_alt;
    float    vx, vy, vz;
    float    roll, pitch, yaw;
    float    pressure;
    int16_t  ax, ay, az;
    int16_t  gx, gy, gz;
    int16_t  hx, hy, hz;      // high g accel
    uint8_t  temp;
    uint8_t  v_batt;
    uint8_t  state;           // first 3 bits state, next 5 bits sats count
    uint8_t  error_code;
    uint8_t  flags;
    uint8_t  flight_number;
    uint8_t  pyro_state;      // bits 0-3 continuity 1-4, bits 4-7 pyro 1-4 active
    uint8_t  RSSI;
    uint16_t CRC16;
} telemetry_pkt_t;

typedef struct {
    uint8_t  flags;           // bit 0 = has_command
    uint8_t  cmd_type;
    uint8_t  cmd_param;
    uint16_t CRC16;
} ack_pkt_t;

#pragma pack(pop)

static_assert(sizeof(telemetry_pkt_t) == 80, "telemetry packet size changed, update flight code too");

// error_code bits
#define ERR_IMU        0x01
#define ERR_BARO       0x02
#define ERR_GPS        0x04
#define ERR_GSM        0x08
#define ERR_SD         0x10
#define ERR_FLASH      0x20
#define ERR_XFER       0x40   // file transfer error
#define ERR_ACK_RX     0x80   // ack received in last cycle

// flags bits
#define FLG_XFER_ACTIVE 0x01
#define FLG_XFER_DONE   0x02
#define FLG_LOGGING     0x04
#define FLG_CMD_RX      0x08  // command received in last cycle
#define FLG_DATA_DROP   0x10
#define FLG_SD_DROP     0x20
#define FLG_GPS_FIX_OK  0x40
#define FLG_GPS_FIX_3D  0x80  // 1 = 3D, 0 = 2D

// commands
#define CMD_NONE          0x00
#define CMD_LED_BLINK     0x01
#define CMD_LED_OFF       0x02
#define CMD_LOG_START     0x03
#define CMD_LOG_STOP      0x04
#define CMD_SET_CON_MODE  0x05
#define CMD_SET_PYRO_MODE 0x06
#define CMD_TRIG_PYRO     0x07

// pyro modes
#define PYRO_1     1
#define PYRO_2     2
#define PYRO_3     4
#define PYRO_4     8
#define PYRO_12    3
#define PYRO_34    12
#define PYRO_12_34 15

#define CMD_QUE_SIZE 8
#define MAX_RETRIES  10

ack_pkt_t cmd_que[CMD_QUE_SIZE];
uint8_t   cmd_sent[CMD_QUE_SIZE];   // transmissions per queued command
uint8_t   cmd_que_count = 0;

bool sent_something = false;

// ---------- helpers ----------

const char* cmdName(uint8_t t)
{
    switch (t)
    {
        case CMD_LED_BLINK:     return "LED_BLINK";
        case CMD_LED_OFF:       return "LED_OFF";
        case CMD_LOG_START:     return "LOG_START";
        case CMD_LOG_STOP:      return "LOG_STOP";
        case CMD_SET_CON_MODE:  return "SET_CON_MODE";
        case CMD_SET_PYRO_MODE: return "SET_PYRO_MODE";
        case CMD_TRIG_PYRO:     return "TRIG_PYRO";
        default:                return "UNKNOWN";
    }
}

bool validPyroMode(uint8_t m)
{
    return m == PYRO_1 || m == PYRO_2 || m == PYRO_3 || m == PYRO_4 ||
           m == PYRO_12 || m == PYRO_34 || m == PYRO_12_34;
}

// integer fixed-point print, e.g. (123456789, 1e7) -> 12.3456789
void printScaled(int32_t v, uint32_t div)
{
    bool     neg = v < 0;
    uint32_t a   = neg ? (uint32_t)(-(int64_t)v) : (uint32_t)v;
    if (neg) Serial.print('-');
    Serial.print(a / div);
    Serial.print('.');
    uint32_t f = a % div;
    for (uint32_t d = div / 10; d > 1 && f < d; d /= 10)
        Serial.print('0');
    Serial.print(f);
}

// prints |b0|b1|b2|b3|  (channel 1 first)
void printPyroBits(uint8_t nibble)
{
    Serial.print('|');
    for (uint8_t i = 0; i < 4; i++)
    {
        Serial.print((nibble >> i) & 1);
        Serial.print('|');
    }
}

void printCmdDesc(const ack_pkt_t &c)
{
    Serial.print(cmdName(c.cmd_type));
    if (c.cmd_type == CMD_SET_CON_MODE || c.cmd_type == CMD_SET_PYRO_MODE)
    {
        Serial.print(F(" param="));
        Serial.print(c.cmd_param);
    }
}

// "0b0011" -> binary, otherwise decimal
bool parseParam(const String &s, uint8_t &out)
{
    if (s.length() == 0) return false;
    long v = 0;
    if (s.startsWith("0b"))
    {
        String b = s.substring(2);
        if (b.length() == 0 || b.length() > 8) return false;
        for (unsigned i = 0; i < b.length(); i++)
        {
            if (b[i] != '0' && b[i] != '1') return false;
            v = (v << 1) | (b[i] - '0');
        }
    }
    else
    {
        for (unsigned i = 0; i < s.length(); i++)
            if (!isDigit(s[i])) return false;
        v = s.toInt();
    }
    if (v < 0 || v > 255) return false;
    out = (uint8_t)v;
    return true;
}

bool enqueue(uint8_t type, uint8_t param)
{
    if (cmd_que_count >= CMD_QUE_SIZE)
    {
        Serial.println(F("queue full, command rejected"));
        return false;
    }
    ack_pkt_t &c = cmd_que[cmd_que_count];
    memset(&c, 0, sizeof(c));
    c.flags     = 0x01;
    c.cmd_type  = type;
    c.cmd_param = param;
    cmd_sent[cmd_que_count] = 0;
    cmd_que_count++;

    printCmdDesc(c);
    Serial.print(F(" added to queue, queue size: "));
    Serial.println(cmd_que_count);
    return true;
}

// FIFO pop
void dequeue()
{
    for (uint8_t i = 1; i < cmd_que_count; i++)
    {
        cmd_que[i - 1]  = cmd_que[i];
        cmd_sent[i - 1] = cmd_sent[i];
    }
    if (cmd_que_count) cmd_que_count--;
}

void printHelp()
{
    Serial.println(F("--- HELP ---"));
    Serial.println(F("ON / OFF      green LED blink on / off"));
    Serial.println(F("LOG / SLG     start / stop logging"));
    Serial.println(F("CON <mode>    set pyro continuity-check mode"));
    Serial.println(F("PYM <mode>    set pyro fire mode"));
    Serial.println(F("FIRE          queue pyro trigger (sent immediately, once)"));
    Serial.println(F("<mode> = decimal or 0b binary, valid values:"));
    Serial.println(F("  1=P1  2=P2  4=P3  8=P4  3=P1+2  12=P3+4  15=all"));
    Serial.println(F("  e.g.  CON 3   PYM 0b1100"));
    Serial.println(F("Commands resend every cycle until the flight confirms (max 10)."));
    Serial.println(F("TRIG_PYRO is sent once, never retried."));
    Serial.println(F("------------"));
}

// ---------- setup ----------
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

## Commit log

2025-01-29 adding the project files
    [on_board_pcb.kicad_pcb, on_board_pcb.kicad_sch]
2025-01-29 added the symbols and footprints in an organized way
    [on_board_pcb.kicad_pcb, on_board_pcb.kicad_sch]
2025-02-06 added lora footprint
2025-02-06 completed LoRa RFM95W Footprint
2025-02-07 added symbol and footprint for arduino nano
2025-02-07 95% of adxl377 footprint added and fixed an error in adxl377 symbol
2025-02-08 added AMS1117 footprint
2025-02-08 fixed LSMD6S0 symbol and footprint
2025-02-18 finished schematic
    [on_board_pcb.kicad_sch]
2025-02-18 added some images and schematic pdf
2025-02-18 made pcb
    [on_board_pcb.kicad_pcb]
2025-04-02 preliminary pcb routing
    [on_board_pcb.kicad_pcb, on_board_pcb.kicad_sch]
2025-04-12 p1 board semifinal
    [on_board_pcb.kicad_pcb, on_board_pcb.kicad_sch]
2025-04-12 added updated schematic. minor cosmetic changes
2025-08-05 arduino sketches and some images
2026-02-14 added rev-2 board
    [Avionics_Board_Rev_2.kicad_pcb, Avionics_Board_Rev_2.kicad_sch]
2026-02-14 started working.
    [Avionics_Board_Rev_2.kicad_pcb, Avionics_Board_Rev_2.kicad_sch]
2026-02-21 in progess
    [Avionics_Board_Rev_2.kicad_sch]
2026-02-21 progress on schematic and pcb
    [Avionics_Board_Rev_2.kicad_pcb, Avionics_Board_Rev_2.kicad_sch]
2026-02-21 more work
    [Avionics_Board_Rev_2.kicad_pcb]
2026-02-22 modified gsm to be a jst connector
    [Avionics_Board_Rev_2.kicad_pcb, Avionics_Board_Rev_2.kicad_sch]
2026-02-22 changes to schematic
    [Avionics_Board_Rev_2.kicad_pcb, Avionics_Board_Rev_2.kicad_sch]
2026-02-27 schematic changes
2026-03-01 schematic and pcb commit -1
    [Avionics_Board_Rev_2.kicad_pcb, Avionics_Board_Rev_2.kicad_sch]
2026-03-04 resistor values added
    [Avionics_Board_Rev_2.kicad_sch]
2026-03-04 values changed 4/3/26
    [Avionics_Board_Rev_2.kicad_sch]
2026-03-05 switch added 1
    [Avionics_Board_Rev_2.kicad_pcb, Avionics_Board_Rev_2.kicad_sch]
2026-03-05 switch update 2
    [Avionics_Board_Rev_2.kicad_pcb]
2026-03-06 Modification 1 on 5 march
    [Avionics_Board_Rev_2.kicad_pcb]
2026-03-06 Modification 2 5 march
    [Avionics_Board_Rev_2.kicad_pcb]
2026-03-06 updated foot prints
    [Avionics_Board_Rev_2.kicad_pcb]
2026-03-06 corrected buckconverter and drive mos
    [Avionics_Board_Rev_2.kicad_pcb, Avionics_Board_Rev_2.kicad_sch]
2026-03-06 patch work 5 march
    [Avionics_Board_Rev_2.kicad_pcb]
2026-03-07 modification 1 7 mmarch
    [Avionics_Board_Rev_2.kicad_pcb, Avionics_Board_Rev_2.kicad_sch]
2026-03-07 Modification 2 march 7
    [Avionics_Board_Rev_2.kicad_pcb]
2026-03-07 Modification 3 7th march
    [Avionics_Board_Rev_2.kicad_pcb, Avionics_Board_Rev_2.kicad_sch]
2026-03-07 QR added
    [Avionics_Board_Rev_2.kicad_pcb]
2026-03-08 final additions , v-2.0.0
    [Avionics_Board_Rev_2.kicad_pcb]
2026-03-08 gerber files
    [Avionics_Board_Rev_2-B_Cu.gbr, Avionics_Board_Rev_2-B_Mask.gbr, Avionics_Board_Rev_2-B_Paste.gbr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]
2026-04-08 feat: add GSM state enum and ring buffer structure
    Current Changes
    - introduced the architecture by objectifying the events during the operation of SMS send/recieve
    - introduced gsm_state_t for future FSM implementation
    - added ring buffer structure for UART data handling
    - no integration with UART or parser yet
    - need to look over the gsm_state_t on whether could be transferred to the GSM.h file instead over here
    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
2026-04-17 added an interrupt function
2026-09-24 fixed IMU errors , added GPS functionality
    [main.cpp]
2026-09-24 added in supporting programs/ arduino sketches
2026-10-07 Implemented pyro code, fixed gps parsing, Implemented dual logging relaible transfer to sd, added new commands BMP 280 issues pending updated ground station code to reflect the firmware changes
    [Ground_Station.ino, PYRO.h, main.cpp]
